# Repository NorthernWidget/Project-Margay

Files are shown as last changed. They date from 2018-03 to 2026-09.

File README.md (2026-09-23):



# Project-Margay

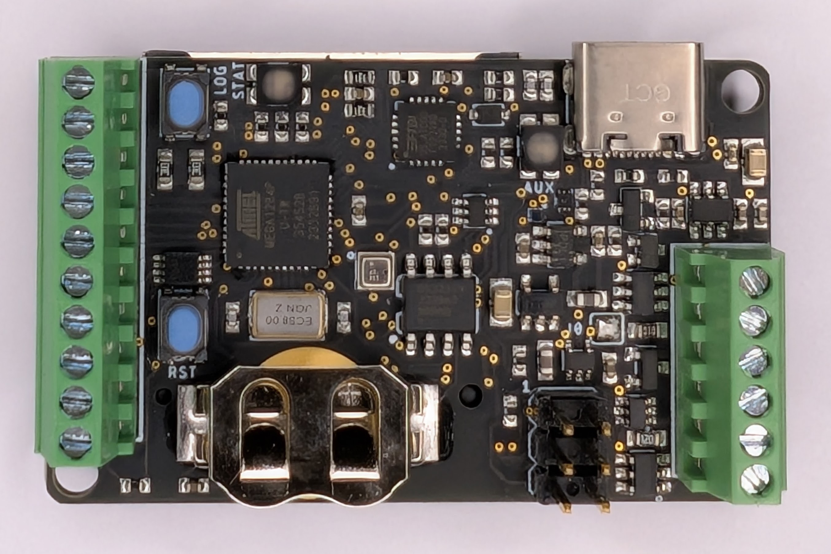
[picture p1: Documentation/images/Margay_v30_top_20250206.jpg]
Margay v3.0, top view


***Margay data logger v3.0.*** *Top side showing ATmega1284p processor, USB-C connector, screw terminal I/O on both sides, and LOG/STAT/RST buttons.*

Project Margay is a micro-scale environmental data logger based on the ALog series. It trades I/O capabilities for cost and size, resulting in a simple yet capable logger.

## Citation

If you use this data logger in a publication, please cite (temporary citation until a dedicated Margay paper is published):

**Wickert, A. D., K. R. Barnhart, W. H. Armstrong, M. Romero, B. Schulz, G.-H. C. Ng, C. T. Sandell, J. La Frenierre, S. B. Penprase, M. Van Wyk de Vries, and K. R. MacGregor (2024), [Automated ablation stakes to constrain temperature-index melt models](https://doi.org/10.1017/aog.2024.21), *Ann. Glaciol.*, *64*(92), 425–438, doi:10.1017/aog.2024.21.**

## Namesake

Due to its small size and adaptability to its environment, Project Margay owes its name to the small Margay cat native to the forests of Central and South America.

A margay, yawning

***A yawning margay cat***

## Technical Specifications

### Electronic Hardware
This includes a description of the PCB and component functionality

#### Features:
* ATMega1284p Processor
* 3.3v Logic
* On board full size SD card (for ease of field use)
* Extremely low sleep current
* Input voltage designed for use with easy to find alkaline batteries
* 0.1" Pitch headers can be populated with header pins and placed on a breadboard for prototyping

### Current iteration:

#### v3.0

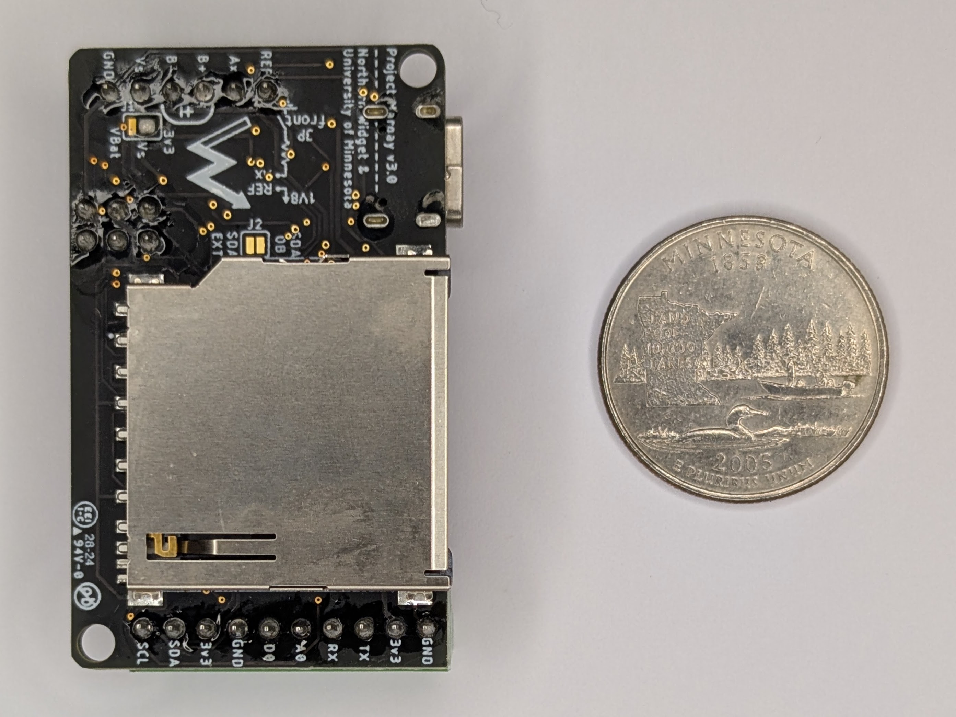
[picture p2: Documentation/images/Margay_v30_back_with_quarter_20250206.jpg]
Margay v3.0, back with SD card and quarter for scale


***Margay data logger v3.0, back side.*** *Full-size SD card for data storage. US quarter (24.3 mm diameter) shown for scale.*

Changes from v2.2:
* USB-C connector (replacing micro-USB)
* Increased mounting hole sizes to fit #4 screws
* Moved one passive component to accommodate the larger holes

All electrical specifications and pinout are otherwise identical to v2.2. Annotated pinout diagrams are in the [Pinout and board interfaces section below](#pinout-and-board-interfaces) and apply directly to v3.0.

### Past Iterations:

#### Features:
* ATMega644p Processor
* 3.3v Logic
* On board full size SD card (for ease of field use)
* Extremely low sleep current
* Input voltage designed for use with easy to find alkaline batteries
* 0.1" Pitch headers can be populated with header pins and placed on a breadboard for prototyping

#### v0.0 (Retired)
**Features** <br>
I<sub>Q</sub> = 1.6mA <br>
I<sub>out</sub> = 50mA, max (Regulated power supplied to sensors) <br>
V<sub>in</sub> = 3.3 ~ 5.5v <br>

**IO**:
* 1 I2C Bus
* 1 SPI Bus, with up to 2 CS pins
* 1 PWM Channel (output configurable to 3.3v or VBat via a jumper on bottom of board)
* RGB Status LED
* Auxiliary LED
* Reset Button
* Reconfigurable Button

#### v1.0
**Features** <br>
I<sub>Q</sub> = 2.5&mu;A <br>
I<sub>out</sub> = 50mA, max (Regulated power supplied to sensors) <br>
V<sub>in</sub> = 3.3 ~ 5.5v (Reverse polarity protected) <br>

**IO**
* 1 ADC, 18 bit
* 1 I<sup>2</sup>C Bus
* 1 SPI Bus, with up to 2 CS pins
* 1 PWM Channel (output configurable to 3.3v or VBat via a jumper on bottom of board)
* RGB Status LED
* Auxiliary LED
* Reset Button
* Reconfigurable Button

#### v2.0
**Features** <br>
I<sub>Q</sub> = <2.5&mu;A (Estimated) <br>
I<sub>out</sub> = 200mA, max (Regulated power supplied to sensors) <br>
V<sub>in</sub> = 3.3 ~ 5.5v (Reverse polarity protected) <br>

**IO**
* 1 ADC, 18 bit
* 1 I<sup>2</sup>C Bus
* 1 UART Channel
* 2 GPIO Pins (one configurable as an 8 bit ADC)
* 1 PWM Channel (output configurable to 3.3v or VBat via a jumper on bottom of board)
* RGB Status LED
* Auxiliary LED
* Reset Button
* Reconfigurable Button

#### v2.2
**Features** <br>
I<sub>Q</sub> = 1.68&mu;A <br>
I<sub>out</sub> = 200mA, max (Regulated power supplied to sensors) <br>
V<sub>in</sub> = 3.3 ~ 5.5v (Reverse polarity protected) <br>

**IO**
* 1 ADC, 18 bit
* 1 I<sup>2</sup>C Bus
* 1 UART Channel
* 2 GPIO Pins (one configurable as an 8 bit ADC)
* 1 PWM Channel (output configurable to 3.3v or VBat via a jumper on bottom of board)
* RGB Status LED
* Auxiliary LED
* Reset Button
* Reconfigurable Button

### Electronic Software and Firmware

* Programmable using the Arduino IDE https://www.arduino.cc/en/software
* Custom bootloader and board definition for ATMega1284p available via https://github.com/NorthernWidget/Arduino_Boards
* Custom libraries from Northern Widget and the open-source community
  * Primary data-logger functions
  * Libraries available with each sensor, exposing a standard interface
* Open-source licensing via GNU GPL 3.0

### Pinout and board interfaces
Pinout is listed on bottom of board. The pinout is identical across v2.2 and v3.0.

Margay v2.2, top annotated

***Margay data logger with pins, connectors, and interactive items annotated, top side.***

**Pins are colored following this convention:**
* Ground: black
* Positive voltage: red
* Universal Serial Asynchronous Receiver--Transmitter (UART or USART) bus: blue
* Digital I/O: gray
* Analog measurement system: green
* I2C bus: purple

*The jumper on the front of the board, to the right of "B+" and "Ax", connects an on-board reference resistor (10 kOhm in our builds) with the analog pin Ax to create a voltage divider in which the sensor between Ax and REF is on the GND side of the voltage divider.*

Margay v2.2, bottom annotated

***Margay data logger annotated, bottom side.*** This is where the labels for the above pins are printed.

In this pinout, the name of each pin is shown, as well as the group of pins which it belongs to, a detailed description of the pins and callouts follows:

#### Pins:
* 3v3, the switched 3.3v output rail, this rail can be turned on and off to disconnect power consumptive external devices
* GND, the main output ground
* BAT+, the positive connection for the battery line, voltage range 3.3v ~ 5.5v
* BAT-, Negative battery connection, ***note: this pin is NOT interchangeable with GND, as BAT- is reverse voltage protected to prevent damage from plugging the battery in backwards***
* Vs, this is the switched PWM output, the voltage of this output is determined by a solder jumper on the bottom of the board, controlled by `VSwitch_Pin` - See information of limits and configuration below

* MOSI, this is the master out, slave in, pin for the SPI bus, which doubles as **D5** when SPI and SD card are not used
* MISO, this is the master in, slave out, pin for the SPI bus, which doubles as **D6** when SPI and SD card are not used
* SCK, this is the clock line for the SPI bus, which doubles as **D7** when SPI and SD card are not used
* CS, this is the chip select pin for the SPI bus, which doubles as both **D11** and **INT1** when external SPI is not used (Can be used even when SD card is used)

* SCL, this is the dedicated serial clock line for the I2C bus
* SDA, this is the dedicated serial data line for the I2C bus

#### Callouts:
1. This is the auxiliary LED, which indicate TX and RX status using red and blue channels, green channel is controlled by `BuiltInLED` pin
2. This is the USB connection (USB-C on v3.0; micro-USB on v2.x), which can be used for both programming via the Arduino IDE and serial monitoring
3. This is the primary RGB status LED, where the individual channels are controlled by **D15**, **D14**, and **D13**
4. This is the reconfigurable push-button, generally used to initiate logging, it is read by `LogInt` pin
5. This is the hardware reset button, which will force the micro to return to the initial state after code upload
6. This is the ICSP header, which can be used to burn the bootloader to the board or write programs to the chip without using the USB and bootloader

#### Onboard Pins:
Pin Name | Pin Number (v0.0) | Pin Number (v1.0) | Pin Number (v2.x) | Function
-------- | ----------------- | ----------------- | ----------------- | --------
`SD_CS` | D4 | D4 | D4 | Chip select pin on SD card
`SD_CD` | D1 | D1 | D1 | Card detection pin for SD card, active low, AUX power must be on to use
`BuiltInLED` | D19 | D20 | D20 | Connected to green channel on **AUX** LED, on when pin is low
`RedLED` | D13 | D13 | D13 | Connected to red channel on **STAT** LED, on when pin is low
`GreenLED` | D15 | D15 | D15 | Connected to green channel on **STAT** LED, on when pin is low
`BlueLED` | D14 | D14 | D14 | Connected to blue channel on **STAT** LED, on when pin is low
`VRef_Pin` | A2 | A2 | A3 | Analog pin to read 1.8v on board reference, AUX power must be on to use
`ThermSensePin` | A1 | A1 | A1 | Analog pin to read thermistor voltage divider, AUX power must be on to use
`BatSensePin` | A0 | A0 | A2 | Analog pin to read battery voltage divider, AUX power must be on to use
`VSwitch_Pin` | D3 | D3 | D12 | Connected to MOSFET driver for **Vs** pin, active low
`Ext3v3Ctrl` | D12 | D19 | D22 | Turns on AUX power, active low
`I2C_SW` | N/A | D12 | D21 | Switches between on board I2C and external I2C
`PG` | D18 | D18 | D18 | Power good pin from core 3v3, can be used to test if core 3v3 is stable, pulled low when power is not stable
`ExtInt` | D11 | D11 | D11 | External interrupt and external chip select pin
`RTCInt` | D10 | D10 | D2 | Interrupt connected to RTC /INT line, active low
`LogInt` | D2 | D2 | A4 | Interrupt connected to **LOG** button, active low

#### VSwitch Power Limits/Configuration:
Jumper Selected | Logger Power Source | Current Limit, Avg [mA] | Power Limit, Avg [W] 
--------------- | ------------------- | ---------------------- | -------------------- 
VMain | USB | 220 | 0.5 
VMain | Bat | 500 | 2.25 
3v3 | USB | 220 | 0.5 
3v3 | Bat | 450 | 2.0

Note: Instantaneous current may exceed these values — these values correspond to the time-averaged power consumption. This distinction is most important when driving a load via PWM.

## On-board Devices

### I2C

| **Device** 	| **Default address** 	| **Reprogrammable address** 	| **Function** 	|
|---	|---	|---	|---	|
| [DS3231](https://github.com/NorthernWidget/DS3231_Logger) 	| 0x68 	| N 	| Real-time clock 	|
| [MCP3421](https://github.com/NorthernWidget/MCP3421) 	| 0x6A 	| N 	| ADC 	|
| [BME280](https://github.com/NorthernWidget/BME_Library) 	| 0x77 	| N 	| On-board barometric pressure, temperature, and relative humidity 	|

### SPI

* SD Card

### UART (USART)

* FTDI USB-Serial converter

## Assembly

Assembling this data logger is possible by hand with sufficient skill and the following tools:
* Temperature-controlled soldering iron
* Hot-air rework station
* Equipment for stenciling with solder paste
* ESD-safe tweezers and workstation
* Solder wick

Mechanized assembly by a professional circuit-board assembly house, which is available in many parts of the world, may be preferred due to the complexity of this data logger board.

## Programming

### Downloading and installing the Arduino IDE

Go to https://www.arduino.cc/en/software and download the IDE for your operating system. The web editor does not support custom libraries and will not work for this project. Install the IDE and open it before continuing.

For additional setup guidance, see the [Northern Widget tutorial](https://docs.northernwidget.com/tutorial/).

### Installing the bootloader

Before a data logger can receive programs via USB, it must have a *bootloader* installed. You can read more about bootloaders here: https://www.arduino.cc/en/Hacking/Bootloader.

The bootloader is loaded via the 6-pin ICSP (ISP) header using an in-circuit system programmer. Many programmers work:
* The official [AVR ISP mkII](http://ww1.microchip.com/downloads/en/DeviceDoc/Atmel-42093-AVR-ISP-mkII_UserGuide.pdf) (no longer produced but available used)
* Using an [Arduino as an ISP](https://www.arduino.cc/en/tutorial/arduinoISP)
* The versatile [Olimex AVR-ISP-MK2](https://www.olimex.com/Products/AVR/Programmers/AVR-ISP-MK2/open-source-hardware)
* The [Adafruit USBtinyISP](https://www.adafruit.com/product/46)

***Important note for Linux users:*** You must supply permissions to the Arduino IDE for it to use the ICSP, or run the IDE with `sudo`.

To install the bootloader:

1. Open the Arduino IDE and install the Northern Widget board definitions: https://github.com/NorthernWidget/Arduino_Boards — the Margay uses the **TLog v1** definition.
2. Select ***ATMega1284p 8MHz*** under *Tools → Board → Northern Widget Boards*.
3. Plug the Margay into your computer via USB (USB-C on v3.0; micro-USB on v2.x) to power it.
4. Plug your ISP into your computer and onto the 6-pin ICSP header. The ribbon cable should face away from the board; if programming fails, try flipping the connector.
5. Go to *Tools → Programmer* and select your programmer.
6. Go to *Tools → Burn Bootloader*. Within a few seconds you will see a success or failure message.

***Note: Download and install drivers for your ISP before use.***

### Hardware test sketch

The [`MargaySetup`](Software/MargaySetup/MargaySetup.ino) sketch verifies every hardware subsystem over the serial monitor at 38400 baud. It also handles serial number programming (`SN Set` / `SN Read`). See the [Full hardware test command reference](#full-hardware-test-command-reference) table below.

Install these libraries before uploading (see [Arduino manual install guide](https://www.arduino.cc/en/Guide/Libraries)):
* [DS3231](https://github.com/NorthernWidget/DS3231) — real-time clock
* [MCP3421](https://github.com/NorthernWidget/MCP3421) — on-board ADC
* SD — bundled with the Arduino IDE

### Data logging

For data logging, use the [Margay_Library](https://github.com/NorthernWidget/Margay_Library). It manages sleep/wake, SD writes, RTC reads, and on-board sensor sampling automatically. See the [Sample code](#sample-code) section below.

Install these libraries manually from GitHub (see [Arduino manual install guide](https://www.arduino.cc/en/Guide/Libraries)):
* [Margay_Library](https://github.com/NorthernWidget/Margay_Library)
* [DS3231_Logger](https://github.com/NorthernWidget/DS3231_Logger)
* [NW_MCP3421](https://github.com/NorthernWidget/MCP3421)
* [BME](https://github.com/NorthernWidget/BME_Library)
* [SdFat](https://github.com/greiman/SdFat) — available via *Tools → Manage Libraries*

### Setting the serial number

Upload the [MargaySetup](Software/MargaySetup/MargaySetup.ino) sketch, open the serial monitor at **38400 baud**, and type `SN Set` followed by a carriage return or newline. You will be prompted for three 4-digit hexadecimal fields:
* **Board type:** `0x4D03` for Margay v3.0; `0x4D02` for v2.2 (full series: v0.0 = `0x4D00`, v1.0 = `0x4D01`). If you built your own board, do not use these codes — they are reserved for Northern Widget recordkeeping.
* **Group ID:** Used to denote collaborative projects vs. internal use vs. general sales.
* **Unique ID:** A monotonically increasing number.

To read back the serial number, type `SN Read`.

### Full hardware test command reference

The same sketch provides a serial command interface at **38400 baud** for testing all individual hardware subsystems. Send a command followed by a carriage return or newline. Continuous tests run until a carriage return is sent to stop them.

Command | Description
--------|------------
`SD` | Writes a random value and short string to the SD card, reads it back, reports PASS/FAIL
`Clock` | Sets the RTC to a known time, waits 5 seconds, reads it back, reports PASS/FAIL
`I2C` | Scans the I2C bus and prints the address of every device found
`ADC Disp` | Continuously prints voltages for the on-board reference, thermistor, battery, and external ADC (Ax)
`IO` | Toggles the VSwitch and ExtInt pins
`PG` | Reads the Power Good pin and reports PASS/FAIL
`Power` | Toggles the external 3.3V rail on and off
`Button` | Waits 2 seconds for the Log button to be pressed and reports if detected
`LED` | Cycles through each channel of the RGB and AUX LEDs
`SN Set` | Sets the serial number in EEPROM (see above)
`SN Read` | Reads back the serial number from EEPROM

### Using Custom Software (Developer)
As we provide all information about on board pins and their functionality, it is easy for a user to write their own code in the Arduino IDE to leverage the hardware capabilities of the Margay to whatever degree is desired. To do this, the Northern Widget board file can be used (as described above), or the **[MightyCore](https://github.com/MCUdude/MightyCore)** board files can be used. These are the board files the Northern Widget ones were based on, but allow for more compilation options for the user. Full instructions for installation and use are provided on the MightyCore GitHub page.

For **v2.0 and later** (ATmega1284p), the recommended settings are:

Setting | Value
--------|------
`Board` | `ATmega1284`
`Pinout` | `Standard`
`Clock` | `8MHz External`
`Compiler LTO` | `Disabled`
`Variant` | `1284P`
`BOD` | `2.7v`

For **v0.0 and v1.0** (ATmega644p), the recommended settings are:

Setting | Value
--------|------
`Board` | `ATmega644`
`Pinout` | `Standard`
`Clock` | `8MHz External`
`Compiler LTO` | `Disabled`
`Variant` | `644P / 644PA`
`BOD` | `2.7v`

#### Sample code

`Margay_NoSensors.ino`

```c++
#include "Margay.h"
// Include any sensor libraries.
// The Northern Widget standard interface is demonstrated here.
//Sensor mySensor;

// Instantiate classes
// Sensor mySensor; (for any Northern Widget standard sensor library)
Margay Logger(MODEL_3v0);  // defaults to MODEL_3v0 if omitted; update for older hardware

// Empty header to start; will include sensor labels and information
String header;

// I2CVals for sensors
// Add these for any sensors that you attach
// These are used in the I2C device check (for the warning light)
// But at the time of writing, the logger should still work without this.
uint8_t I2CVals[] = {};

// Number of seconds between readings
// The Watchdog timer will automatically reset the logger after approximately 36 minutes.
// We recommend logging intervals of 30 minutes (1800 s) or less.
// Intervals that divide cleanly into hours are strongly preferable.
uint32_t updateRate = 60;

void setup(){
    // No sensors attached; header may remain empty.
    // header = header + mySensor.getHeader(); // + nextSensor.getHeader() + ...
    Logger.begin(I2CVals, sizeof(I2CVals), header);
}

void loop(){
    Logger.run(update, updateRate);
}

String update() {
    initialize();
    //return mySensor.getString(); // If a sensor were attached
    return ""; // Empty string for this example: no sensors attached
}

void initialize(){
    //mySensor.begin(); // For any Northern Widget sensor
                        // Other libraries may have different standards
}
```

### Reference

A full index of the public variables and functions within the Margay data logger library is available at https://github.com/NorthernWidget/Margay_Library.

## Field operator's guide

The [Margay Operations Guide (PDF)](Documentation/MargayGuide_20220622.pdf) covers field operation in printable form.

***Note: Logger will not be able to wake up unless the clock (RTC) is powered.***

The RTC (DS3231M) is powered exclusively by the **CR1220 coin cell** mounted on the back of the board. This is a separate power source from the main battery pack — the logger cannot wake from sleep if the coin cell is missing, dead, or making poor contact, even if the main batteries are fully charged.

**Cold-weather deployments:** Standard CR1220 cells (Li-MnO₂) are rated to −20°C and may fail at temperatures common in subarctic and arctic field sites. Observed clock failures in cold deployments are likely caused by the coin cell browning out at low temperature. The coin cell is the sole RTC power source during sleep — the main battery does not power the RTC between readings.

- For deployments down to −30°C: replace the CR1220 with a [**Panasonic BR1220**](https://www.digikey.com/en/products/detail/panasonic-bsg/BR1220-BE/447510) (Li-CFx chemistry, rated −30°C to +85°C, drop-in replacement).
- For deployments below −30°C: use a [**Panasonic BR1225A**](https://www.digikey.com/en/products/detail/panasonic-bsg/BR1225A-BE/447512) (Li-CFx, rated −40°C to +125°C). The BR1225A is 2.5mm thick vs. 2.0mm for the 1220 — the on-board holder (Linx BAT-HLD-012-SMT) officially supports both sizes.

### Logging Start
Logging begins automatically once power is applied. If error conditions are found, they will be indicated by status lights, but the logger will attempt to continue if possible. The following should represent the light sequence.

- On power application
	- `AUX` light will illuminate **green**, will stay on while testing
- After testing is complete
	- `AUX` light will turn **off**
	- `STAT` light will illuminate with various colors depending on the status of the logger
    - See "Status Codes" under "Troubleshooting" below for details
	- `STAT` light will flash **long-short-short blue** to indicate logging has begun (older firmware: 5× long blue flash)

### Checking recorded data
1. After initializing, wait 2–3 minutes.
2. Follow the **SD card swap / Download** steps below to retrieve the SD card.
3. Verify that all data are recorded at the proper (UTC) time.
4. Verify that valid values are recorded for all sensors.
5. If files are not present, replace the SD card, check all connections, and re-initialize.

### SD card swap
1. Turn battery pack **off**.
2. Remove SD card. Label it and put it somewhere safe.
3. Insert a freshly labeled SD card.
4. Turn battery pack on and re-initialize.

### Downloading data
1. Turn battery pack **off**.
2. Remove SD card.
3. Insert SD card in computer.
4. Navigate to the most recent log file: `NW → <serial_number> → Log<number>.txt`
5. Save the file in a well-labeled and organized location.
6. Safely eject the SD card.
7. Re-initialize the logger.

### Troubleshooting
If an error code is received try the following steps:

**General**
* Disconnect and reconnect power, both USB and battery ([Turn it off and back on again](https://i.imgur.com/Yj6dB3W.gif))
* Verify the quality of all screw terminal connections by gently tugging on the wires and making sure they stay in place, if not, remove and re-tighten the connection
* Ensure sensors and/or cables are not damaged, this can result in shorts or other problems
* Make sure batteries have sufficient voltage to run the logger, when the battery voltage drops below *3.3v*, malfunctions can occur

#### Status Codes

The second LED (STAT) will have one of the colors below.

**Green**: All systems check out OK, logging will proceed

**Orange**: A sensor system is not registering properly, some sensor data may be missing or incorrect
* Verify correct polarity of sensor connection
* Ensure the right sensor is connected
* Verify the screw terminals are well connected to the wires (a loose connection can cause a failure)
* Make sure battery power is applied, some sensors can fail otherwise

**Cyan**: Clock time is incorrect, but logger is otherwise working correctly
* Connect the logger to a computer and reset the clock using the [Northern Widget Time Set GUI](https://github.com/NorthernWidget/SetTime_GUI)
* Note and record the wrong time if the logger has been out in the field, alongside the current (correct) time, to correct the prior measurements

**Pink**: (looks like purple to some people): SD card is not inserted
* Insert the SD card, or make sure card is fully seated

**Red**: Critical on-board component is not functioning correctly, such as SD card or clock; Logging will likely not be able to proceed
* Attempt power cycle
* Try different SD card
* Disconnect all sensors
* If none of the previous steps remove the red light, contact [Northern Widget](http://www.northernwidget.com/contact/) for further support

**Yellow, Fast Blinking**: <50% battery capacity
* Replace batteries

**Red, Fast Blinking**: Batteries <3.3V, voltage too low to properly function
* *If* this error occurs while also connected over USB, check proper connection of batteries
* Replace batteries

## Developer Notes

+ (**v0.0 / v1.0 only**) When using power from the external rail (the 3v3 on the screw terminals) it is always advised to have a battery connected to the board, even if connected via USB. The USB connection is able to power the core components, but not the external rail. This was resolved in v2.0.
+ (**v0.0 / v1.0 only**) When using I<sup>2</sup>C on the device, external pullups (4.7k&Omega; ~ 10k&Omega;) are required. If using devices strictly on-board, the internal pullups on the ATmega may be sufficient, but adding the capacitance of an external sensor cable often causes problems since the internal pullups are very weak. Dedicated switchable on-board pullups were added in v2.0.
+ (**All models**) The external power rails and the switched battery rail should be enabled in hardware by default, however, it is our recommendation to explicitly define these pins (`Ext3v3Ctrl`) as outputs and drive them `LOW` even if you never intend to switch them on and off. This prevents the rails from inadvertently being turned off due to a transient on the floating control line.

## NW-Device-Specification schema

Margay's serial number scheme is [Schema 0](https://github.com/NorthernWidget/NW-Device-Specification) — the original 8-byte NW identity block, predating the formal specification. Schema 1 formalizes it as Page 0 and defines a putative Page 1 for the case where Margay acts as an I²C peripheral of a higher-level device (e.g., a cellular gateway or satellite modem). **Margay has no current I²C peripheral interface; Page 1 is hypothetical.**

### Current EEPROM serial number (Schema 0)

Eight bytes at `EEPROM[length−8]` through `EEPROM[length−1]` (bytes 4088–4095 on the ATmega1284P), big-endian uint16 per field, written by MargaySetup `SN Set`:

| Bytes | Field | Example (Margay v3.0) |
|---|---|---|
| 0–1 | Board type | `0x4D03` (`'M'` = 0x4D, revision 3) |
| 2–3 | Group ID | operator-assigned |
| 4–5 | Unique ID | monotonically increasing |
| 6–7 | FirmwareID | `0x0000` (hardcoded) |

Displayed as `XXXX-XXXX-XXXX-XXXX` in hex (e.g. `4D03-0001-0042-0000`).

### Proposed register layout (NW-Device-Specification Schema 1)

**Page 0 (0x00–0x1F) — Identity (EEPROM)**

Block 2 directly formalizes the existing 8-byte serial number with no data loss. The board type encoding (`'M'` = 0x4D high byte, revision index low byte) already follows the Schema 1 convention.

```
Block 0 (0x00–0x07)   Core identity
  0x00        0x01                           Schema (NW-Device-Specification v1)
  0x01–0x06   'M','a','r','g','a','y'        Device name (6 bytes)
  0x07        0x00                           Reserved

Block 1 (0x08–0x0F)   Version
  0x08        HW major
  0x09        HW minor
  0x0A        FW patch
  0x0B–0x0D   0x00,0x00,0x00                Unused (combined repo convention)
  0x0E–0x0F   0x00,0x00                     Reserved

Block 2 (0x10–0x17)   Serial number
  0x10–0x11   0x4D,0x03                     Board type ('M'=0x4D, revision index)
  0x12–0x13   [manufacture]                 Group ID
  0x14–0x15   [manufacture]                 Unique ID
  0x16–0x17   0x00,0x00                     FirmwareID (legacy, reserved)

Block 3 (0x18–0x1F)   Integrity + administration
  0x18–0x1C   0x00 ×5                       Reserved
  0x1D        0x00                          Magic byte (reserved; purpose TBD)
  0x1E        [computed]                    CRC-8 of bytes 0x00–0x1D
  0x1F        0x00                          I²C address (unassigned; Margay is
                                            currently I²C controller only)
```

**Page 1 (0x20–0x3F) — Logger status (SRAM) — HYPOTHETICAL**

Margay is currently an I²C controller only and has no peripheral interface. This layout is proposed for the case where a future version acts as an I²C peripheral of a higher-level device. A natural peripheral address would be `0x4D` (ASCII `'M'`).

Subsystem table (same index rules as a sensor's chip table):

| Index | Subsystem |
|---|---|
| 0 | SD card |
| 1 | DS3231M RTC |
| 2 | BME280 onboard environment |
| 3 | Sensor bus |
| 4 | Battery |

Block 0 (0x20–0x27) is the universal block defined by [NW-Device-Specification](https://github.com/NorthernWidget/NW-Device-Specification#page-1-sensor-data): status (ready, per-chip fault bits, pan-fault), control (trigger, chip select, sleep), reading counter, device config byte at 0x26, latched fault code at 0x27. Device data begins at 0x28. Config (0x26): reserved. Logger state continues on Page 3 (0x60–0x7F).

```
Block 1 (0x28–0x2F)   Battery
  0x28        Bat %        uint8, 0–100
  0x29–0x2A   Bat voltage  uint16, 0.01 V
  0x2B–0x2F   Reserved

Block 2 (0x30–0x37)   BME280 — onboard environment
  0x30–0x31   Temperature  int16, 0.01 °C
  0x32–0x33   Humidity     uint16, 0.01 %RH
  0x34–0x37   Pressure     uint32, 0.01 hPa

Block 3 (0x38–0x3F)   DS3231M — RTC
  0x38–0x3B   Timestamp    uint32, Unix time (seconds since 1970-01-01 UTC)
  0x3C–0x3D   Temperature  int16, 0.01 °C
  0x3E–0x3F   Reserved

Page 3, Block 0 (0x60–0x67)   Logger state
  0x60–0x61   Ext interrupts  uint16, accumulated count
  0x62–0x63   Log file #      uint16
  0x64–0x67   Log interval    uint32, seconds
```

No Page 2. Battery discharge curve coefficients and Steinhart–Hart thermistor constants are hardcoded in the library; no per-unit calibration is stored.

## NW-Device-Specification — Schema 1, Page 0

Implements [NW-Device-Specification](https://github.com/NorthernWidget/NW-Device-Specification) Schema 1. The 32-byte identity block (Page 0) is stored at the top of EEPROM:

```
Block 0:  Schema=0x01, Name='M','a','r','g','a','y',0x00
Block 1:  HW major=[mfr], HW minor=[mfr], FW patch=[mfr], 0x00,0x00,0x00, Reserved
Block 2:  Board type=0x4D03 ('M'=0x4D, rev 3), Group ID=[mfr], Unique ID=[mfr], FirmwareID=0x0000
Block 3:  Reserved, Magic=0x4E, CRC=[computed], I2C address=0x00 (controller; no peripheral interface)
```

## Acknowledgments

Support for this project provided by:

UMN ESCI

NSF

<br/>
<br/>
<br />Hardware and documentation are licensed under a <a rel="license" href="http://creativecommons.org/licenses/by-sa/4.0/">Creative Commons Attribution-ShareAlike 4.0 International License</a>. Software in the <code>Software/</code> directory is licensed under the <a href="https://www.gnu.org/licenses/gpl-3.0.en.html">GNU General Public License v3</a>.

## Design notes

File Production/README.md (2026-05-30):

# Production

This folder contains bills of materials, Gerber packages, and assembly files for each Margay hardware version.

## Contents

### Bills of Materials

| File | Version | Date | Notes |
|---|---|---|---|
| `Margay_BoM_2v2_-2021-05-10.csv` | v2.2 | 2021-05-10 | Assembly BoM (soldered components) |
| `Margay_BoM_2v3_-_2023-03-16.csv` | v3.0 day 1 | 2023-03-16 | "v2.3" was a one-day working name; board became v3.0 |
| `Margay_BoM_3v0_-_2023-03-17.csv` | v3.0 | 2023-03-17 | Assembly BoM: soldered components; used for Caltronics production run |
| `Margay_BoM_3v0_board_-_2023-03-17.csv` | v3.0 | 2023-03-17 | Board BoM: non-soldered items inserted into the board (coin cell, SD card) |

### Gerber and assembly packages

| File | Version | Date | Notes |
|---|---|---|---|
| `Margay_3v0_proto_2023-05-01.zip` | v3.0 proto | 2023-05-01 | Prototype Gerber run; detailed top silkscreen; same copper as production |
| `Margay_3v0_2023-08-01.zip` | v3.0 production | 2023-08-01 | Production Gerbers used for Caltronics assembly run |
| `Margay_3v0.mnt` | v3.0 | — | Pick-and-place / centroid file for SMT assembly |

### Quotes

| File | Date | Notes |
|---|---|---|
| `CaltronicsQuote_2023-08-01.zip` | 2023-08-01 | Assembly quote from Caltronics for the v3.0 production run |

---

## Submitting to a fab house

Each Gerber ZIP contains a `CAMOutputs/` folder exported from Eagle with the following structure:

```
CAMOutputs/
  Assembly/
    Margay.txt          — BoM (Eagle-exported)
    PnP_Margay_front.txt — Pick-and-place, top side
    PnP_Margay_back.txt  — Pick-and-place, bottom side
  DrillFiles/
    drill_1_16.xln      — Excellon drill file
  GerberFiles/
    copper_top.gbr / copper_bottom.gbr
    silkscreen_top.gbr / silkscreen_bottom.gbr
    soldermask_top.gbr / soldermask_bottom.gbr
    solderpaste_top.gbr / solderpaste_bottom.gbr
    profile.gbr         — Board outline
    gerber_job.gbrjob   — Job file (KiCAD/Gerber viewer metadata)
```

Submit the full ZIP to the PCB fabricator. For assembly, additionally provide the pick-and-place files and the assembly BoM CSV (`Margay_BoM_3v0_-_2023-03-17.csv`). The board BoM (`Margay_BoM_3v0_board_-_2023-03-17.csv`) covers the coin cell and SD card inserted after assembly and is not sent to the fab house.

> **Note:** When these packages are restructured into versioned subdirectories, each subfolder will contain its own README with version-specific notes.

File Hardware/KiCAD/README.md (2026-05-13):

# Hardware/Margay_2 — Eagle-to-KiCAD port, current working version (work in progress)

This is the most current KiCAD design for the Margay v3.0, representing the active Eagle-to-KiCAD port.

**Current state:** schematic is split across three hierarchical sheets (`Margay_1/2/3.kicad_sch`) imported from Eagle via `Margay-eagle-import.kicad_sym`. PCB layout (`Margay.kicad_pcb`) is also present. Both are works in progress and have not been verified against the v3.0 production Gerbers.

Tracking issue: https://github.com/NorthernWidget/Project-Margay/issues/41

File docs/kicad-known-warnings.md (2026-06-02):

# KiCAD "Update PCB from Schematic" — Known Warnings

Running **Update PCB from Schematic** in KiCAD consistently produces 8 warnings of the form "No net found for symbol X pin Y." All are benign and carry through from the original Eagle design.

## The 8 warnings

| Component | Pin | Reason |
|---|-----|---|
| J4 (USB-C, GCT USB4105-GF-A) | M1 | Mechanical mounting tab — no electrical net by design |
| J4 (USB-C, GCT USB4105-GF-A) | M2 | Mechanical mounting tab — no electrical net by design |
| J4 (USB-C, GCT USB4105-GF-A) | M3 | Mechanical mounting tab — no electrical net by design |
| J4 (USB-C, GCT USB4105-GF-A) | M4 | Mechanical mounting tab — no electrical net by design |
| U6 (TPS797 LDO) | 3 (EN) | EN pin not modeled in Eagle-imported symbol; pad exists on footprint but has no symbol pin. EN floating = always on — intentional. |
| U10 (TLV3691 comparator) | 5 (HYST) | Hysteresis pin intentionally left floating — no external hysteresis resistor used |
| U11 (MIC9409 load switch) | 3 (FLAG) | Open-drain fault flag output intentionally unused |

## Why they can't be easily suppressed

- **J4 M1–M4**: The M pins exist in the Eagle-imported symbol but are not broken out visibly on the schematic sheet. No-connect markers cannot be placed on invisible pins.
- **U6 pin 3**: The EN pin is absent from the Eagle-imported TPS797 symbol entirely. Adding it would require editing the symbol and re-wiring the schematic instance.
- **U10 pin 5, U11 pin 3**: Pins exist in the symbol but are not visible on the schematic sheet. No-connect markers could suppress these if the pins are exposed.

## What to do

Nothing — these warnings do not affect manufacturing output, DRC, or board function. They are accepted as known informational noise from the Eagle→KiCAD migration.

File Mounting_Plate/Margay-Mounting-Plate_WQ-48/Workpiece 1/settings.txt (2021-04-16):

Material type: ABS
Material dimensions: 190.5 mm x 139.7 mm x 3.175 mm
Bit: 0.0625 in, Upcut

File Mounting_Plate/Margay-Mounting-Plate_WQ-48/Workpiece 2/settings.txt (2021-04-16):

Material type: ABS
Material dimensions: 139.7 mm x 190.5 mm x 3.175 mm
Bit: 0.0625 in, Upcut

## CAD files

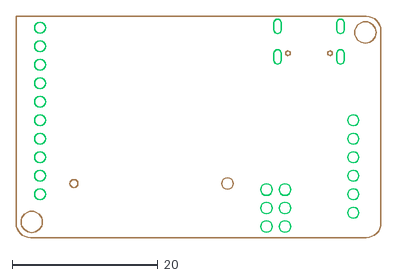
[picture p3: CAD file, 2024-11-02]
Hardware/Margay_Outline.dxf
50.1 x 30.4

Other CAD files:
3Dprint/BatteryMount_Strap.SLDPRT
Hardware/Margay_PCB_3v0.STL
3Dprint/BatteryMount_WH10.SLDPRT
3Dprint/MargayMount_WH02_lid.SLDPRT
3Dprint/MargayMount_WH10.SLDPRT
3Dprint/StencilMount_Margay.SLDPRT
3Dprint/BatteryMount_Strap.STL
3Dprint/BatteryMount_WH10.STL
3Dprint/MargayMount_WH02_lid.STL
3Dprint/MargayMount_WH10.STL
3Dprint/StencilMount_Margay.STL

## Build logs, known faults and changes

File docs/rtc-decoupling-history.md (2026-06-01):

# RTC Power & Decoupling History

## Field Motivation

The Margay is a scientific data logger. Every record it produces is timestamped by the DS3231M RTC. When the RTC resets — losing the current time and returning to its epoch (January 1, 2000) — every subsequent log entry carries a wrong timestamp. The data is not merely imprecise; it is scientifically worthless. A sensor reading without a valid time cannot be placed in context, correlated with other measurements, or published.

Instruments are deployed in remote locations — stream gauges in wilderness watersheds, weather stations above treeline, soil sensors in arctic tundra — where servicing is expensive or seasonally impossible. A logger that silently resets its clock may accumulate weeks or months of invalid records before anyone notices. The fix is a site visit; the lost data is unrecoverable.

This is the engineering context behind the circuit changes described below. Keeping the clock running is not a convenience feature — it is the minimum condition for the instrument to do its job.

## Background

The DS3231M real-time clock has two power pins with distinct roles:

- **VCC** — primary power, supplied from the `3V3_AUX` switched rail. This rail is cut during MCU sleep to minimize quiescent current.
- **VBAT** — backup power, supplied from the CR1220 coin cell. The DS3231M switches to VBAT automatically when VCC falls below its internal threshold.

Because `3V3_AUX` is switched off every sleep cycle, the RTC transitions between VCC and VBAT every time the logger sleeps or wakes. The integrity of that handoff is the central concern of this page.

## Version History

### v0.0 and v1.0 — No VBAT decoupling

In the original designs, the VBAT pin connected directly to the coin cell with no decoupling capacitor. The net (`N$31` in the Eagle schematic) had only two members: `RTC1.VBAT` and `BT1.+`.

The `3V3_AUX` rail had minimal bulk decoupling — a single 1 µF capacitor at the LDO output.

**Effect:** When the MCU entered sleep and `3V3_AUX` collapsed, the DS3231M had to switch from VCC to VBAT with no local charge reservoir on VBAT to bridge the transition. The coin cell's ESR and the inductance of the PCB traces meant VBAT could dip transiently at exactly the moment the chip needed it. The DS3231M interpreted this as a power-on reset and cleared its time registers. Symptoms: logger woke up with the clock reset to its epoch (January 1, 2000), usually after a sleep cycle.

This was the primary cause of the RTC-reset failures observed in early field deployments.

### v2.1 — VBAT decoupling capacitor added

A 0.1 µF capacitor (C12, 0402) was added between the coin cell positive rail and the DS3231M VBAT pin. This matches the recommendation in the DS3231M datasheet.

The cap acts as a local charge reservoir: when VCC collapses, VBAT can supply instantaneous current from C12 while the coin cell's ESR settles, preventing the DS3231M from seeing a dip large enough to trigger a reset.

This change substantially reduced the frequency of RTC resets.

### v2.2 — Renumbering, more 3V3\_AUX bulk capacitance, switch topology change

- C12 was renumbered to **C19** (same value: 0.1 µF, 0402). The net was renamed from `N$31` to `VCOIN+`.
- `3V3_AUX` bulk decoupling grew significantly: from ~1 µF (v1.0) to ~21 µF total (C5 0.1 µF + C6 10 µF + C14 1 µF + C15 10 µF). A softer VCC collapse means a gentler handoff to VBAT.
- The `3V3_AUX` power switch was changed to **active-low control logic**, affecting the switching waveform on sleep entry.

### v3.0 — No change to RTC power circuit

v3.0 (USB-C, #4 mounting holes) made no changes to RTC power or decoupling. The circuit is identical to v2.2.

## Current Circuit (v2.2 / v3.0)

| Pin | Net | Connected to |
|-----|-----|---|
| VCC | `3V3_AUX` | Switched LDO output; cut during sleep |
| VBAT | `VCOIN+` | Coin cell (BT1) ∥ C19 (0.1 µF, 0402) |

The VBAT line is **not** connected to the always-on core 3.3 V rail.

## Remaining Vulnerability

The 0.1 µF cap on VBAT cannot sustain the RTC indefinitely. Two failure modes remain:

1. **Depleted or missing coin cell.** If VBAT has no source, C19 discharges in microseconds and the RTC resets.
2. **Cold-temperature coin cell brownout.** Standard CR1220 cells (Li-MnO₂) are rated to −20°C. Below that, internal resistance rises sharply and the cell may not be able to maintain VBAT above the DS3231M's minimum (2.3 V). This was the cause of observed clock failures in subarctic deployments.

Cold-temperature mitigation (available since v3.0): replace the CR1220 with a Panasonic BR1220 (rated −30°C) or BR1225A (rated −40°C, 2.5 mm thick — fits the Linx BAT-HLD-012-SMT holder). See the README for details.

## Proposed Future Improvement — VBAT Spoof (Issue #43)

To address both failure modes, v3.1 may route the always-on core 3.3 V rail to DS3231M VBAT through a Schottky diode (~0.3 V drop → ~3.0 V on VBAT, within the DS3231M's 2.3–5.5 V spec), with the existing C19 retained as the decoupling cap.

The coin cell would remain as a last-resort backup if the main pack is exhausted; the Schottky diode prevents backfeed into the core rail if the coin cell voltage ever exceeds it.

Pros and cons are discussed in [Issue #43](https://github.com/NorthernWidget/Project-Margay/issues/43).

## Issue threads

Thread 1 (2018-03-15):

Add Primary MOSFET

bschulz1701, 2018-03-15:
Add mosfet to switch the battery voltage input to all outputs (Vdd of comparators, and BatSense voltage divider)

bschulz1701, 2018-05-04:
Added along with 2 stage battery switch and secondary regulator

Closed 2018-05-04.

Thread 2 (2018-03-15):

Fix power setup for FTDI

bschulz1701, 2018-03-15:
Add mosfet/switching arraignment to get FTDI to be disconnected from power when micro USB voltage is not applied

Should disconnect 3v3out, and VCCIO

bschulz1701, 2018-04-10:
Fixed using the following circuit, where VCCIO, 3V3OUT, and RESET# lines of the FTDI converter are connected to 3V3_FTDI, this circuit allows for power to be supplied to the main 3V3 line by the converter in the FTDI (powered only over USB), however it prevents reverse power flow badness.

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

**Before fully closing issue, this circuit should be tested in hardware with the addition of LEDs**

Closed 2018-05-04.

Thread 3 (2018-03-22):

Fix address issue with ADC

bschulz1701, 2018-03-22:
on board ADC has same address as one used on TP-Downhole
Options:
-use different ADC hardware address (different part)
-be able to turn off external power separately from on board power
-Power ADC from GPIO pin

bschulz1701, 2018-04-10:
Fixed by creating an isolated on board I2C bus in addition to an external I2C bus, isolation was performed using the addition of a SN74LVC1G3157 SPDT analog switch. This issue was solved by the resolution of #7

bschulz1701, 2021-02-26:
Problem confirmed to be solved via addition of analog switch to separate `SDA_OB` and `SDA_EXT`

Note: this issue is being closed due to hardware functionality confirmed, need to resolve issue #24 in order to settle issue

Closed 2021-02-26.

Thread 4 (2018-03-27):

Flip I2C connector

bschulz1701, 2018-03-27:
Flip the I2C connector around, so that it matches with the Project Heptapod pinout

bschulz1701, 2018-05-04:
Fixed by flipping the connector. D'oh!

Closed 2018-05-04.

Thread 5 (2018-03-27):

Add Battery connector

bschulz1701, 2018-03-27:
Add JST battery connector to allow for more easy connection

bschulz1701, 2021-02-26:
After use case consideration, this feature has been put on indefinite hiatus

Closed 2021-02-26.

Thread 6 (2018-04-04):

Fix SD connection

bschulz1701, 2018-04-04:
Add hardware disconnect/isolation for SD card, either by use of N-FET on ground line of SD card, or through some kind of logic buffer

bschulz1701, 2018-05-04:
Fixed with addition of logic buffer

Closed 2018-05-04.

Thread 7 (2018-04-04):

Isolated I2C Bus

bschulz1701, 2018-04-04:
Add some kind of isolation to the I2C bus so that power is not drawn through the data lines of the I2C devices

bschulz1701, 2019-04-12:
Should be dealt with by using external pullups to `3V3_AUX` bus

bschulz1701, 2021-02-26:
Fixed by use of `3V3_AUX` as pullup source as opposed to `3V3`. This allows parasitic power to be eliminated to the fullest extent possible.

Note: This hardware fix allows for prevention of parasitic leakage, but it does not guarantee it. In order to ensure it does not occur, the I2C lines must be placed into the appropriate `INPUT` or `OUTPUT` - `LOW` condition during sleep state. Failure to do this, or placing lines in `INPUT_PULLUP` state, will result in parasitic leakage.

Closed 2021-02-26.

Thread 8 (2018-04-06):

Add I2C pullups

bschulz1701, 2018-04-06:

bschulz1701, 2018-04-10:
Fixed with addition of pull-ups (D'oh!)

bschulz1701, 2018-04-10:
Do we really need I2C pullups?

bschulz1701, 2018-07-18:
Add I2C pullups to the 3v3 External rail, this will fix startup problems and prevent lockups due to I2C after sleep, etc

Closed 2019-04-12.

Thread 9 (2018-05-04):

Use PG as cutoff

bschulz1701, 2018-05-04:
Use PG pin to connect to reset line (or some similar setup) to prevent writing to SD card when voltage is below cutoff (As this can cause corruption to files), alternative would be to use CRC check on SdFat writing

bschulz1701, 2021-02-26:
Currently `PG` is only provided as an input to the micro, it is reliant on the user to test `PG` via firmware before making writes to SD card in order to prevent corruption.

Note: The issue of SD cards being corrupted by voltages lower than 3.3V has been reported anecdotally, it has not been observed with the Margay system and can not be directly confirmed via SD card documentation. That being said, it is good idea to ensure power is stable and within operational ranges before making reads and writes regardless.

bschulz1701, 2021-09-08:
This could be implemented in hardware, but would require a fair bit of testing to make sure you don't get yourself into a corner on the power system (stuck in a reset loop, etc). This issue was added as the Cave Pearl group noted that you could corrupt the data on an SD card if you performed an undervoltage write (this is reasonable as if the voltage is not sufficient you may not be able to set the SRAM blocks, resulting in a check error). We have never seen this happen on any of our loggers, even when drained below the 3.3V + dropout (~175mV if I remember  correctly). Not to say it can't happen, which is why I put this issue as a long term want.
If you look at a micro SD card [datasheet](https://www.kingston.com/datasheets/SDCIT-specsheet-8gb-32gb_en.pdf), the supply voltage is rated down to 2.7V. The buffer we are using to communicate with the SD card (SN74AUP3G34, U5 on v2.2) is rated all the down to 0.8V. So in the dropout region (2.875V < Vin < 3.475V) the buffer should drive the SD card perfectly correctly and not provide a low voltage to the device. The micro is also able to work fine down to that voltage (discounting potential overclocking issues, but that is separate). All this to say that we have a pretty wide range after the device goes into dropout to detect low input voltage and stop logging before corruption occurs.
I think rather than trying to implement this in hardware (given the low likelihood of an issue and that it would take a bit of time better spent on more pressing issues) we should just implement it in firmware. Before writing to the SD card check the `PG` pin and do not write if it is low, instead print an error message or flash a low voltage light, etc. This should protect equally well against the issues and may be preferable, since it can give indication of the status rather than just being stuck in reset. I never love the idea of being dependent on mission critical elements in the firmware, but in this case, probably the better/simpler solution. Especially due to the fact we have not been contending with this problem. I have not yet tried to induce a corruption, but from inadvertent low voltage writes, it seems the voltage needs to very low (like 2.5V or less) to cause these kind of issues.

**tl;dr** - We have never observed this problem, this was a want. However, I think this would be better implemented in firmware for several reasons, would be a very simple implementation.

awickert, 2022-05-03:
Now that I have made some more significant changes towards v2.3, would you like to make these towards v3 of the board, such that this is the version that we will publish about?

Or should we keep things as they are and keep a possible hardware implementation (beyond `PG` being broken out) in the future / maybe won't happen?

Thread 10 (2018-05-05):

Add test for alarm pin in hardware test

bschulz1701, 2018-05-05:
Add a feature to test the hardware interrupt pin from the clock, do this by setting up an alarm on the clock, for 1 or 2 seconds, then wait and make sure interrupt gets triggered

bschulz1701, 2021-02-26:
This is a firmware issue and should be ported to the Margay_Library repo. This feature was added as of: 8afa026f7eff719172065aa3b60e5c7ad6d05fd9 (Merge branch 'master' into master, July 9th, 2018)

Recommend this issue be closed, can move to firmware repo for completeness

awickert, 2021-03-01:
Opened and closed an issue in the library repo here for completeness, per @bschulz1701:
https://github.com/NorthernWidget-Skunkworks/Margay_Library/issues/21
Now closing.

Closed 2021-03-01.

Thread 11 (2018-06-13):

Add 2nd analog channel?

bschulz1701, 2018-06-13:
Does it make sense to add a second analog channel for support of some sensor varieties?

bschulz1701, 2021-02-26:
Based on current use cases, we feel a focus on a robust digital interface makes more sense. Can be revisited later, but on extended hiatus.

awickert, 2021-03-01:
I will add "wontfix" and close. In practical use cases, it seems that an inexpensive external ADC breakout (e.g., https://www.adafruit.com/product/1085) is perfectly fine. Indeed, this ADC is well supported by the Adafruit Arduino library, https://github.com/adafruit/Adafruit_ADS1X15. Agree with @bschulz1701 that we could revisit this, but that with a quality I2C interface, we can easily expand the Margay without cramming more on board.

Closed 2021-03-01.

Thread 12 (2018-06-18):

Add BMP280 as on board sensor?

bschulz1701, 2018-06-18:
Add the Bosch BMP280 temp and pressure sensor to the board as an onboard sensor https://www.digikey.com/product-detail/en/bosch-sensortec/BMP280/828-1064-1-ND/6136315

Closed 2019-04-12.

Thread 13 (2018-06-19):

Fix power over USB issue

bschulz1701, 2018-06-19:
When powered over USB, on board power works fine, but external power floats at ~2.5v, which can cause some issues. When powered via battery, everything works fine.

Allow for some kind of bypass between 3.3v onboard to external for this case, or allow a bypass from USB input to battery input??

bschulz1701, 2021-02-26:
This feature was implemented in v0.2 by way of a power MUX to connect `VUSB` to `VMAIN` whenever `VUSB` is present, overriding the battery to preserve power when being supplied via USB. Se `U9` and `U10` in schematic for circuit details. This allows for smooth seamless switchover between supplies, as well as allowing the device to supplied solely via USB for bench top testing without needing to be concerned with batteries

Closed 2021-02-26.

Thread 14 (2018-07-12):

Fix button pad layout

bschulz1701, 2018-07-12:
Make sure button pad layout has been updated and fixed in Cold Silicon Library

[Datasheet](https://www.ckswitches.com/media/1476/pts810.pdf) to verify

bschulz1701, 2018-09-07:
Updated Cold Silicon to reflect proper layout, updated Margay board from there and fixed resulting routing errors

Closed 2018-09-07.

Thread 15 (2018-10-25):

Add Cap on backup battery

bschulz1701, 2018-10-25:
Add capacitor to backup battery to prevent debouncing and clock reset issues?

Closed 2019-04-12.

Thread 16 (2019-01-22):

Add pulldown resistor of `VSWITCH`

bschulz1701, 2019-01-22:
### Issue:
The output of `VSWITCH` can drive a load appropriately, but does not work well as a PWM output to a sensor or other device with high input impedance, since the bulk charge on the FET (Q1) is not dissipated.

### Solution:
Add a pulldown resistor to ground to drain this bulk capacitance after switching. Perform experimentation to determine best value. 1k is sufficient for even fast switching operations (<10us), but may be overly high for power consumption. Ensure result will work at switching frequencies > 100kHz (common PWM frequency)

bschulz1701, 2019-01-22:
### Additional Testing:
Testing revealed the bulk capacitance to be about 160nF, to get a clean square wave (rise + fall < 1%) for a 1kHz frequency (max standard Arduino PWM), need a **pulldown of < 24k&Omega;**
#### Updated Design:
For better performance, may be desirable to use a half bridge CMOS to drive the output

bschulz1701, 2019-01-22:
#### Updated Design:
This problem should be solved by use of MIC94090 load switch (slated to replace discrete mosfet design for v0.2). Use of **MIC94091** (fast turn on **with** output discharge feature), t_rise + t_delay = 0.8us, t_fall + t_delay = 70ns, so total transition time = 870ns, which would be appropriate for a switching signal of **>10kHz** for a <1% transition time.

bschulz1701, 2021-02-26:
The load switch with output discharge was implemented in v0.2 which allowed for push-pull driven outputs, resolving this problem.

Closed 2021-02-26.

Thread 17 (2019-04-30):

Leakage current into TPS2105 (v2 Only)

bschulz1701, 2019-04-30:
### Issue
When the system goes to sleep, the comparator (U4) inputs are both 0v, since the comparator has sufficient hysteresis the output stays set with the state of the last input combination. When the system is just powered over battery, this results in a high output (3.3v) which drives the select pin on the unpowered TPS2105, resulting in ~300nA of leakage current into the switch pin.

When the last power source is USB, the output state of the comparator is low (0v), which eliminates this leakage current.

### Potential Solution
Reconfigure the input/output scheme of the comparator/TPS2105

Switch the inputs on the comparator in order to satisfy the truth table:

| State | Output |
| ------------- | ------------- |
| V<sub>bat/2</sub> > V<sub>3v3FTDI</sub>  | 0 |
| V<sub>bat/2</sub> < V<sub>3v3FTDI</sub>   | 1  |

Then change the power switch device to be the TPS2104 instead of the TPS2105 since the TPS2104 has an inverted logic input, resulting in the same total equivalent logic between voltage input and voltage selected

bschulz1701, 2021-02-26:
Change was implemented in v2.2 (8ca38a50c7f0e3debad69798afdcdab926ccc984), confirmed successful on subsequent fab and testing. Issue can be closed, FIGHT FOR YOUR RIGHT TO ~~PARTY~~ HAVE OPTIMIZED POWER CONSUMPTION!

Closed 2021-02-26.

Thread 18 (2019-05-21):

USB Power Latch (Models < v2.1)

bschulz1701, 2019-05-21:
### Issue:
When USB power is connected while the battery is simultaneously connected, there is a small additional power draw due to voltage mismatches (~160uA @ 4.5v). This draw results in a latching of the USB power switch, such that when the USB is removed, the FTDI draws power parasitically from the battery (~400uA @ 4.5v), this problem persists even in sleep mode and power down.

### Workaround:
If the USB is desired to be connected while battery is also connected (to check battery voltage, system status, etc), it is recommended to minimize this time simply to reduce draw on the battery. Then, once the USB is removed, make sure to **power cycle the battery**, this will fix the latching problem.

#### Updates:
The latching problem has been fixed on models >= `v2.1`, so no power cycle is required. However, the small current draw due to voltage mismatch is still present, so it is still recommended to reduce the time both are connected, simply to preserve the battery charge.

awickert, 2021-03-01:
Closing per @bschulz1701: This has been resolved on newer versions, so the general problem has been solved. This will stay as an archive for those concerned about power draw in prior versions.

Closed 2021-03-01.

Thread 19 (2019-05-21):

Reverse Polarity with USB (Model v0.0)

bschulz1701, 2019-05-21:
### Issue:
When USB power is applied **and** the battery is reverse polarized **destructive heating can occur**.

This issue occurs only when (reverse polarity) battery power is applied, followed by USB power. When this occurs, power is dissipated across `Q2` (the reverse polarity protection diode), causing significant heating.

#### Testing:
The following tests were performed in order to characterize the performance of the reverse current protection
**Test 1:**
USB power applied, **then** reverse polarity battery voltage applied
V<sub>Bat</sub> = 4.5v (power supply)
V<sub>USB</sub> = 5v (power supply)
T<sub>Ambient</sub> = 25&deg;C

| Time [s] | I<sub>Bat</sub> [mA] | T<sub>Q2</sub> [&deg;C] |
| --------  | -------------------------- | ------------------------------  |
| 0 | 16.3 | 25 |
| 15 | 16.3 | 30 |
| 30 | 16.3 | 32 |
| 120 | 16.3 | 35* |

*Stabilized temp

Note: These results are the same for all power cycling conditions for Model > v0.0

**Test 2:**
Reverse battery power applied, **then** USB voltage applied
V<sub>Bat</sub> = 4.5v (power supply)
V<sub>USB</sub> = 5v (power supply)
T<sub>Ambient</sub> = 25&deg;C

| Time [s] | I<sub>Bat</sub> [mA] | T<sub>Q2</sub> [&deg;C] |
| --------  | -------------------------- | ------------------------------  |
| 0 | 16.3 | 25 |
| 5 | 110 | 35 |
| 15 | 126 | 67 |
| 30 | 130 | 85 |
| 60 | 130 | 100 |

### Workaround:
For these older models, it is recommended to connect the battery power with **USB disconnected**, then verify by the presence of status lights that the logger is properly powered. Once this is verified, it is then safe to connect USB in parallel as usual.

awickert, 2021-03-01:
v0.0 is long superceded; closing per @bschulz1701 and leaving this as a warning for anyone using our few pieces of earliest hardware. (Currently just us and two collaborators.)

Closed 2021-03-01.

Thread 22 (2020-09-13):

Installation formatting

morandagny, 2020-09-13:
Installation section needs to be expanded beyond just the current "software" section/created and formatted similar to Resnik/Haar/etc. for consistency/readability/approachability. Also should be sure that during the creation of this installation section if anything is found to be wrong/out of date/buggy to fix that in corresponding areas in other datalogger installation sections. Will double check and make documentation issues on those pages if found.

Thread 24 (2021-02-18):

Off-board I2C nonfunctional

awickert, 2021-02-18:
From conversations with @bschulz1701, I recall this to be an issue in firmware rather than in hardware.

In order for communications to work with any off-board I2C device, we currently are required to solder across the on/off-board I2C jumper on the back (SD card side) of the Margay. We should (a) as a stop-gap, default to solder-jumpering these, and/or in the longer term (b) fix the firmware.

awickert, 2021-02-25:
If this is to remain this way for some time, also consider including this as a note in the documentation update.

awickert, 2021-03-01:
I just opened https://github.com/NorthernWidget-Skunkworks/Margay_Library/issues/22 to reference this from the firmware library. If it turns out to be a firmware issue, we can close this one and move discussion there.

Closed 2021-03-02.

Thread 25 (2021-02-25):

Is soldering J1 to 3v3 (or perhaps Vbat) to set the voltage of Vs required?

awickert, 2021-02-25:
@jbcannon noted in email that on his boards' builds (produced through PCBWay):

"The SD card detection issue appears fixed with this J1 pad jumper (without me having to circumvent the SD card check)... and the function of the Reset button when running on battery is now restored."

@jbcannon was having issues with the reset button when running the "benchtop" sketch (i.e., not sleeping) and with SD card writing when running the standard Margay programs (with sleeping).

Here's the question. Is this an issue with leaving a pin on the [MIC94094YC6-TR](https://www.digikey.com/en/products/detail/microchip-technology/MIC94094YC6-TR/2062452) floating? Or is this some sort of fix that perhaps clamps down a voltage on shoddy hardware and keeps the ship held together? And even if the latter, is it best practice to always select one of these solder-jumper options, in which case we should perhaps include that in the solder stencil Gerber?

awickert, 2021-02-25:
Talking with @bschulz1701 right now.

Yes, it is best to not keep this pin floating, though there is nothing in particular that should cause an issue. @awickert has a Margay built by Caltronics where this is disconnected, but it isn't a problem. But we shouldn't have ill-defined states.

Indeed we do have Vcream already set up to link this to the battery power, so this shouldn't have been disconnected:
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

More generally, there might have been a problem in fab because of the surface tension at the corners of the rectangular pads. **We should switch these on the Margay board to rounded-edge pads (semicircular ones).**

Whe making this change, let's **switch default to 3V3** so the full system is defaulting to the same voltage.

awickert, 2021-03-01:
I have made the change to a 3V3 default connection and have pushed it. The `Vswitch` pin will now default its connection to `3V3_AUX` via the stenciled-on solder-paste jumper.

Revision here: f548f917aa99fd3005058ddd31e623f4deecff98

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

Closed 2021-03-01.

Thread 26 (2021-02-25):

CR1220 required for logger to wake up

awickert, 2021-02-25:
This is the clock battery. Based on comments from @jbcannon, we should make it really clear to users that the logger won't be able to wake up unless the clock (RTC) is powered. This is especially true because users may not even realize that it is the RTC that the CR1220 powers. More documentation is better!

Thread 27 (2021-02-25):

Verify clock-fail error code

awickert, 2021-02-25:
Take the CR1220 out of a Margay. Start it up. Does it:
* Give the proper LED blink code (Cyan blinking)
* Print to serial that it has a clock fail (CLOCK: ERROR)
?

awickert, 2021-03-01:
Note: Close and reopen at firmware library in case this is more a firmware issue.
https://github.com/NorthernWidget-Skunkworks/Margay_Library

Closed 2021-03-02.

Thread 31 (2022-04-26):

Unable to access external ADC while using Margay::run()

ericbarefoot, 2022-04-26:
`Margay:run()` does not permit the user to access the on-board (but also external) ADC. This component is needed to read analog voltages, but cannot be accessed if one is also reading data from an external I2C unit.

Closed 2022-04-26.

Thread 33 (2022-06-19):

Update Xtal (Obsolete)

awickert, 2022-06-19:
8MHz crystal no longer produced:
https://www.digikey.com/en/products/detail/txc-corporation/7A-8-000MAHJ-T/6130668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

Update on board and BoM

Look into any needed changes in decoupling caps, too.

awickert, 2022-10-05:
Digi-Key indicates that this piece is a drop-in replacement (using their new/ish? "myLists" feature) and my first looks confirm this.

https://www.digikey.com/en/products/detail/ecs-inc/ECS-80-12-30-JGM-TR/13968095

Second eyes would be good. Perhaps best to update this part definition in https://github.com/bschulz1701/Cold-Silicon

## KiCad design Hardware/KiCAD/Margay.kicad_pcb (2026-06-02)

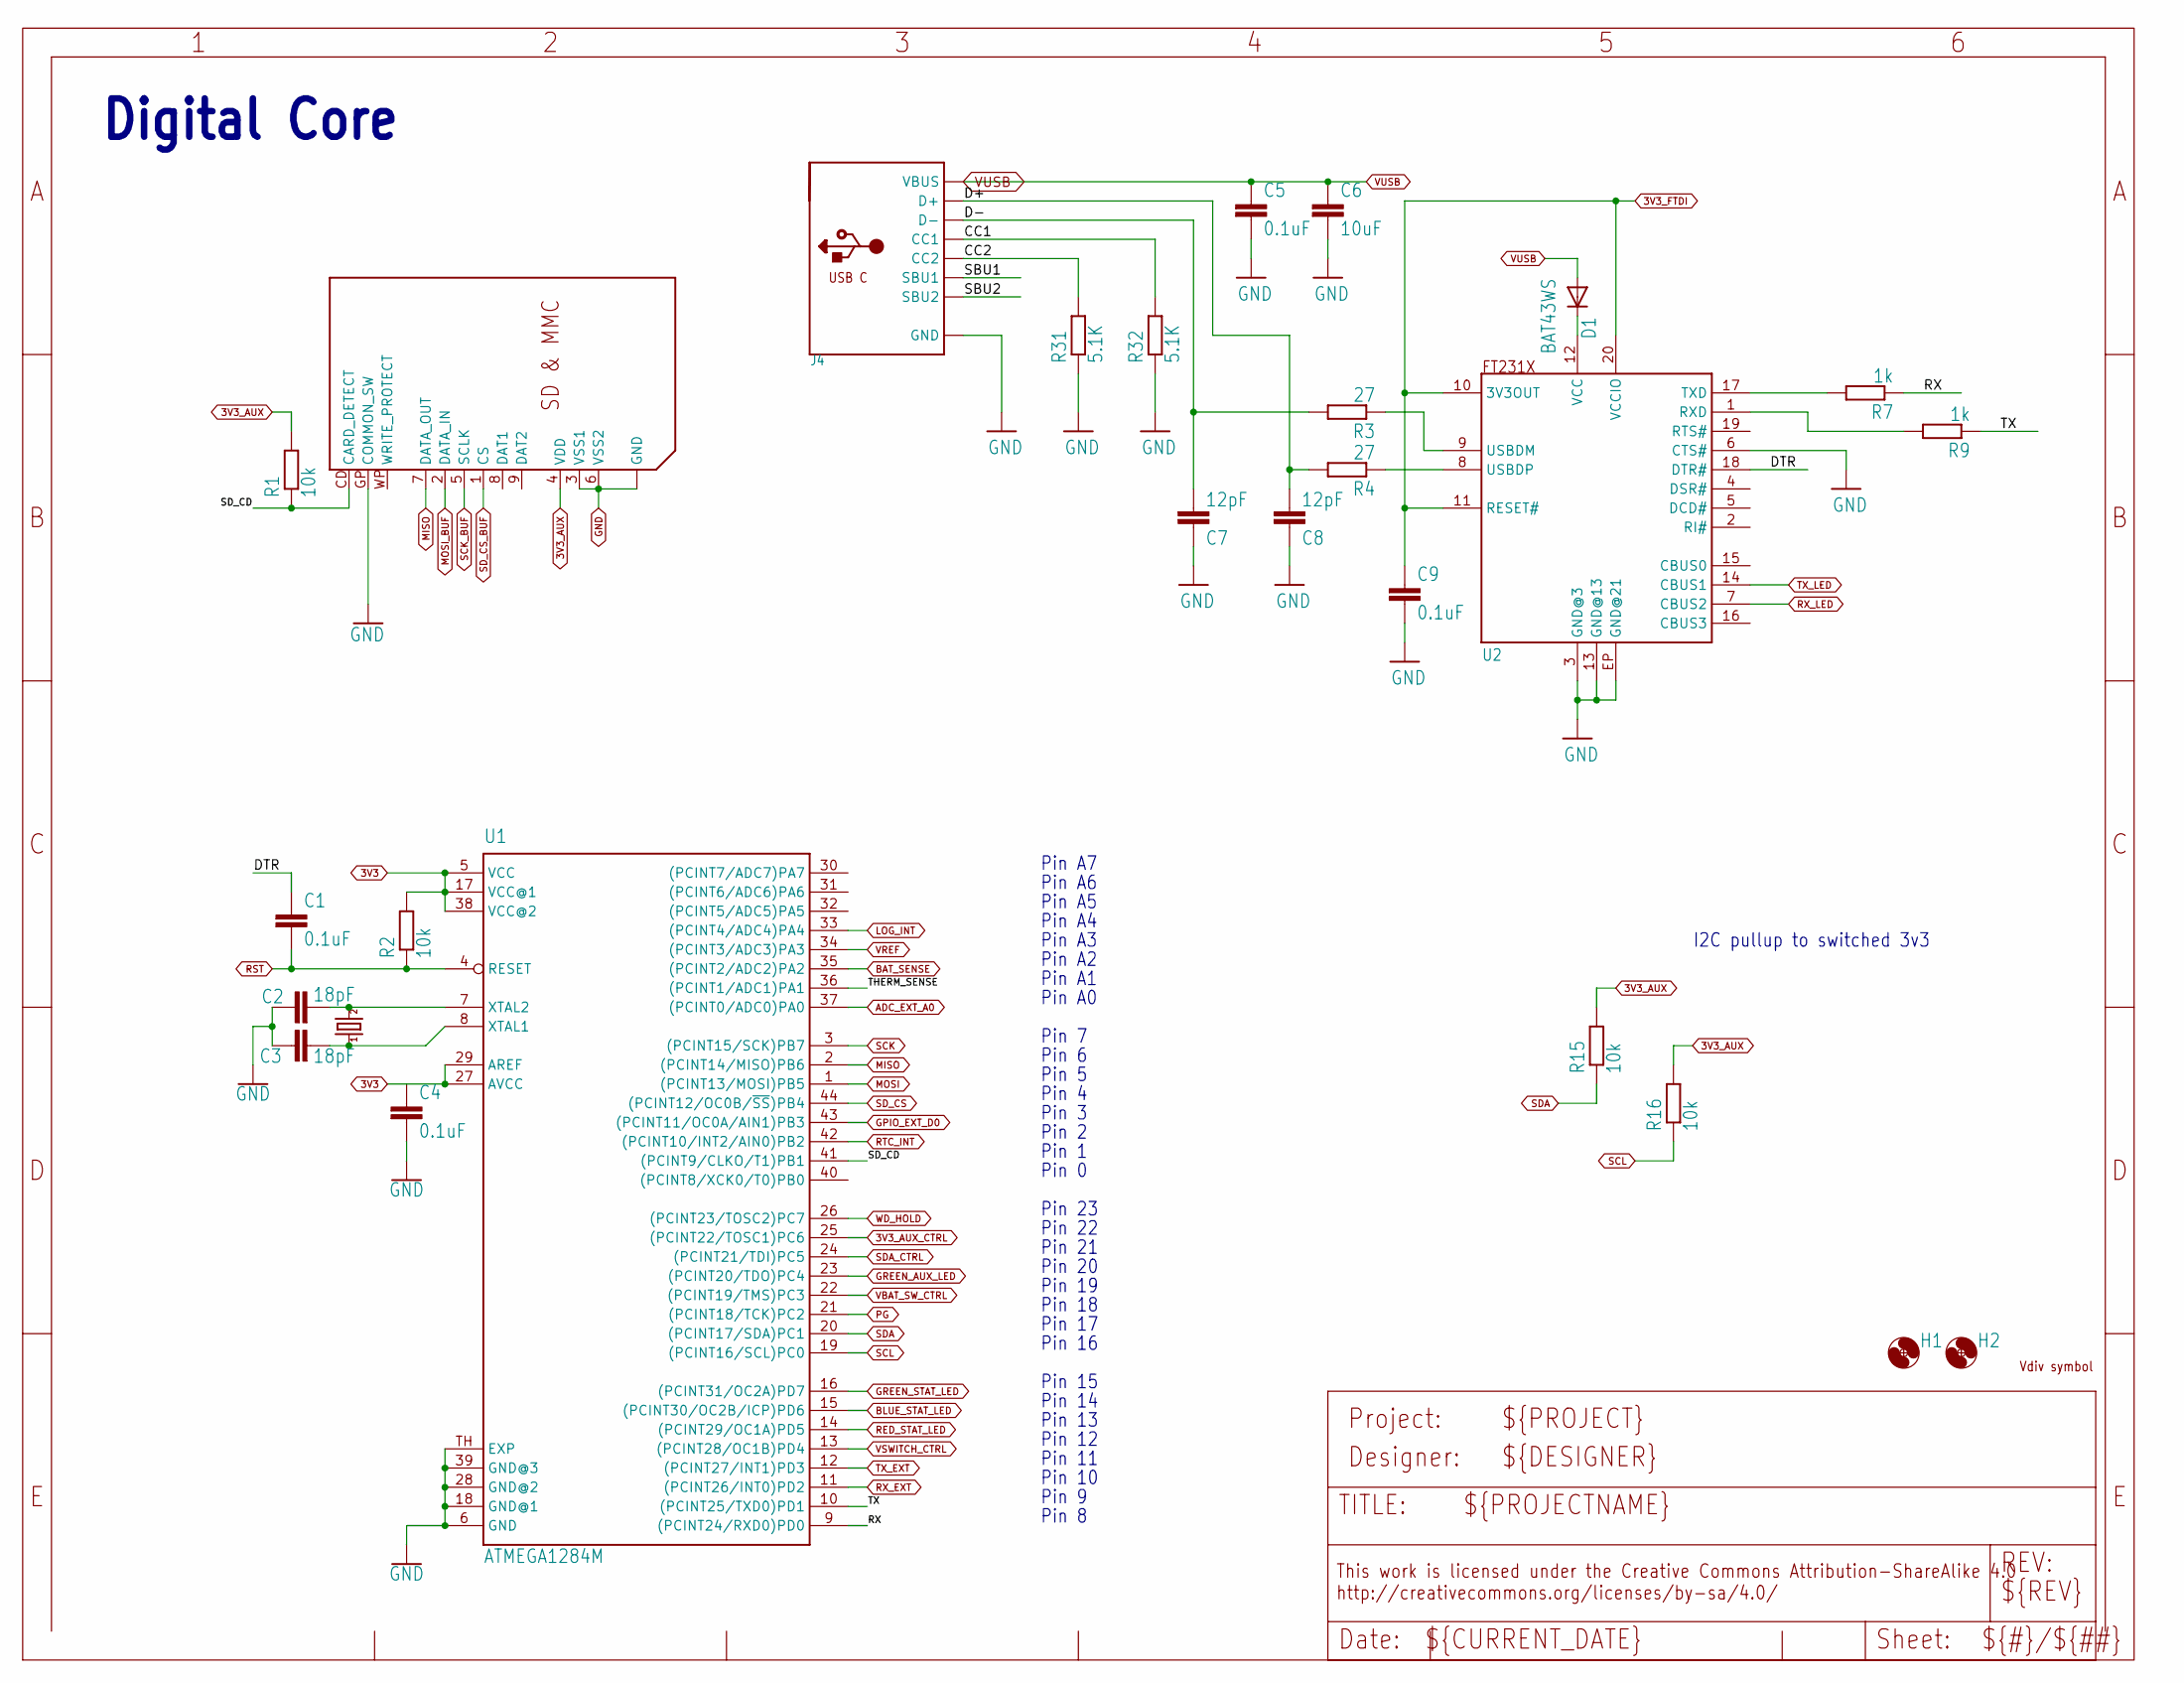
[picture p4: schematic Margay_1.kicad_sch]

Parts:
C1, C4, C5, C9: 0.1uF; C0402; MPN GCM155R71C104KA55D; DIGIKEY 490-4759-1-ND
C2, C3: 18pF; C0402; MPN GCM1555C1H180JA16D; DIGIKEY 490-12650-1-ND
C6: 10uF; C0805; MPN GRM21BR61C106KE15K; DIGIKEY 490-6473-1-ND
C7, C8: 12pF; C0402; MPN CGA2B2C0G1H120J050BA; DIGIKEY 445-5585-1-ND
D1: BAT43WS; SOD323-R; MPN BAT43WS-7-F; DIGIKEY BAT43WS-FDICT-ND
H1, H2: MOUNTING_HOLE4_NP_CLOSE; 4_40_CLOSE; MPN N/A; DIGIKEY DNP
J1: SDMMCWR-CRD; SD_WURTH_WR-CRD; MPN 693063010911; DIGIKEY 732-3817-1-ND
J4: USB_C; USB_C_CUSB31-CFM2AX-01-X; MPN USB4105-GF-A; DIGIKEY 2073-USB4105-GF-ACT-ND
R1, R2, R15, R16: 10k; R0402; MPN RC0402FR-0710KL; DIGIKEY 311-10.0KLRCT-ND
R3, R4: 27; R0402; MPN RC0402FR-0727RL; DIGIKEY YAG3086CT-ND
R7, R9: 1k; R0402; MPN RC0402FR-071KL
R31, R32: 5.1K; R0402; MPN RC0402FR-075K1L; DIGIKEY 311-5.10KLRCT-ND
U1: ATMEGA1284M; MLF44-TH; MPN ATMEGA1284P-MUR; DIGIKEY ATMEGA1284P-MURCT-ND
U2: FT231X-Q; QFN20; MPN FT231XQ-R; DIGIKEY 768-1128-1-ND
U$1: VDIV_MARGAYFULL-VDIV; VDIV_MARGAY_2021; MPN N/A; DIGIKEY DNP
XTAL1: CRYSTAL5X3.2; CRYSTAL_5X3.2_2-SMD; MPN ECS-80-18-30-JGN-TR; DIGIKEY XC2103CT-ND

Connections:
3V3: C4.1, R2.2, U1.5 (VCC), U1.17 (VCC@1), U1.27 (AVCC), U1.29 (AREF), U1.38 (VCC@2); also elsewhere on the board
3V3_AUX: J1.4 (VDD), R1.2, R15.2, R16.2; also elsewhere on the board
3V3_AUX_CTRL: U1.25 ((PCINT22/TOSC1)PC6); also elsewhere on the board
3V3_FTDI: C9.1, U2.10 (3V3OUT), U2.11 (RESET#), U2.20 (VCCIO); also elsewhere on the board
/Margay_1/CC1: J4.A5 (CC1), R32.2
/Margay_1/CC2: J4.B5 (CC2), R31.2
/Margay_1/D+: C8.2, J4.A6 (D+), J4.B6 (D+), R4.2
/Margay_1/D-: C7.2, J4.A7 (D-), J4.B7 (D-), R3.2
/Margay_1/DTR: C1.1, U2.18 (DTR#)
/Margay_1/RX: R7.1, U1.9 ((PCINT24/RXD0)PD0)
/Margay_1/SBU1: J4.A8 (SBU1)
/Margay_1/SBU2: J4.B8 (SBU2)
/Margay_1/SD_CD: J1.CD (CARD_DETECT), R1.1, U1.41 ((PCINT9/CLKO/T1)PB1)
/Margay_1/THERM_SENSE: U1.36 ((PCINT1/ADC1)PA1)
/Margay_1/TX: R9.1, U1.10 ((PCINT25/TXD0)PD1)
ADC_EXT_A0: U1.37 ((PCINT0/ADC0)PA0); also elsewhere on the board
BAT_SENSE: U1.35 ((PCINT2/ADC2)PA2); also elsewhere on the board
BLUE_STAT_LED: U1.15 ((PCINT30/OC2B/ICP)PD6); also elsewhere on the board
GND: C2.1, C3.1, C4.2, C5.2, C6.2, C7.1, C8.1, C9.2, J1.3 (VSS1), J1.6 (VSS2), J1.GP (COMMON_SW), J1.GP2 (GND), J1.GP3 (GND), J1.GP4 (GND), J4.A1B12 (GND), J4.B1A12 (GND), R31.1, R32.1, U1.6 (GND), U1.18 (GND@1), U1.28 (GND@2), U1.39 (GND@3), U1.TH (EXP), U2.3 (GND@3), U2.6 (CTS#), U2.13 (GND@13), U2.EP (GND@21); also elsewhere on the board
GPIO_EXT_D0: U1.43 ((PCINT11/OC0A/AIN1)PB3); also elsewhere on the board
GREEN_AUX_LED: U1.23 ((PCINT20/TDO)PC4); also elsewhere on the board
GREEN_STAT_LED: U1.16 ((PCINT31/OC2A)PD7); also elsewhere on the board
LOG_INT: U1.33 ((PCINT4/ADC4)PA4); also elsewhere on the board
MISO: J1.7 (DATA_OUT), U1.2 ((PCINT14/MISO)PB6); also elsewhere on the board
MOSI: U1.1 ((PCINT13/MOSI)PB5); also elsewhere on the board
MOSI_BUF: J1.2 (DATA_IN); also elsewhere on the board
unnamed: C3.2, U1.8 (XTAL1), XTAL1.OSC1 (1)
unnamed: C2.2, U1.7 (XTAL2), XTAL1.OSC2 (2)
unnamed: R9.2, U2.1 (RXD)
unnamed: R7.2, U2.17 (TXD)
unnamed: R3.1, U2.9 (USBDM)
unnamed: R4.1, U2.8 (USBDP)
unnamed: D1.C, U2.12 (VCC)
PG: U1.21 ((PCINT18/TCK)PC2); also elsewhere on the board
RED_STAT_LED: U1.14 ((PCINT29/OC1A)PD5); also elsewhere on the board
RST: C1.2, R2.1, U1.4 (RESET); also elsewhere on the board
RTC_INT: U1.42 ((PCINT10/INT2/AIN0)PB2); also elsewhere on the board
RX_EXT: U1.11 ((PCINT26/INT0)PD2); also elsewhere on the board
RX_LED: U2.7 (CBUS2); also elsewhere on the board
SCK: U1.3 ((PCINT15/SCK)PB7); also elsewhere on the board
SCK_BUF: J1.5 (SCLK); also elsewhere on the board
SCL: R16.1, U1.19 ((PCINT16/SCL)PC0); also elsewhere on the board
SDA: R15.1, U1.20 ((PCINT17/SDA)PC1); also elsewhere on the board
SDA_CTRL: U1.24 ((PCINT21/TDI)PC5); also elsewhere on the board
SD_CS: U1.44 ((PCINT12/OC0B/~SS)PB4); also elsewhere on the board
SD_CS_BUF: J1.1 (CS); also elsewhere on the board
TX_EXT: U1.12 ((PCINT27/INT1)PD3); also elsewhere on the board
TX_LED: U2.14 (CBUS1); also elsewhere on the board
VBAT_SW_CTRL: U1.22 ((PCINT19/TMS)PC3); also elsewhere on the board
VREF: U1.34 ((PCINT3/ADC3)PA3); also elsewhere on the board
VSWITCH_CTRL: U1.13 ((PCINT28/OC1B)PD4); also elsewhere on the board
VUSB: C5.1, C6.1, D1.A, J4.A4B9 (VBUS), J4.B4A9 (VBUS); also elsewhere on the board
WD_HOLD: U1.26 ((PCINT23/TOSC2)PC7); also elsewhere on the board

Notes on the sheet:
Pin A2
Pin 13
Pin 23
Pin A7
Pin 20
Pin 6
Pin 16
Pin 17
Pin 5
Pin 12
Pin 14
Pin 9
Pin 0
Pin 4
Pin 10
Pin 22
Pin 8
Pin A6
Pin 7
Pin A4
Pin 15
Digital Core
Pin 3
Pin A1
Pin 18
Pin A0
Pin 19
Pin 1
Pin 21
I2C pullup to switched 3v3
Pin A3
Pin A5
Pin 11
Pin 2

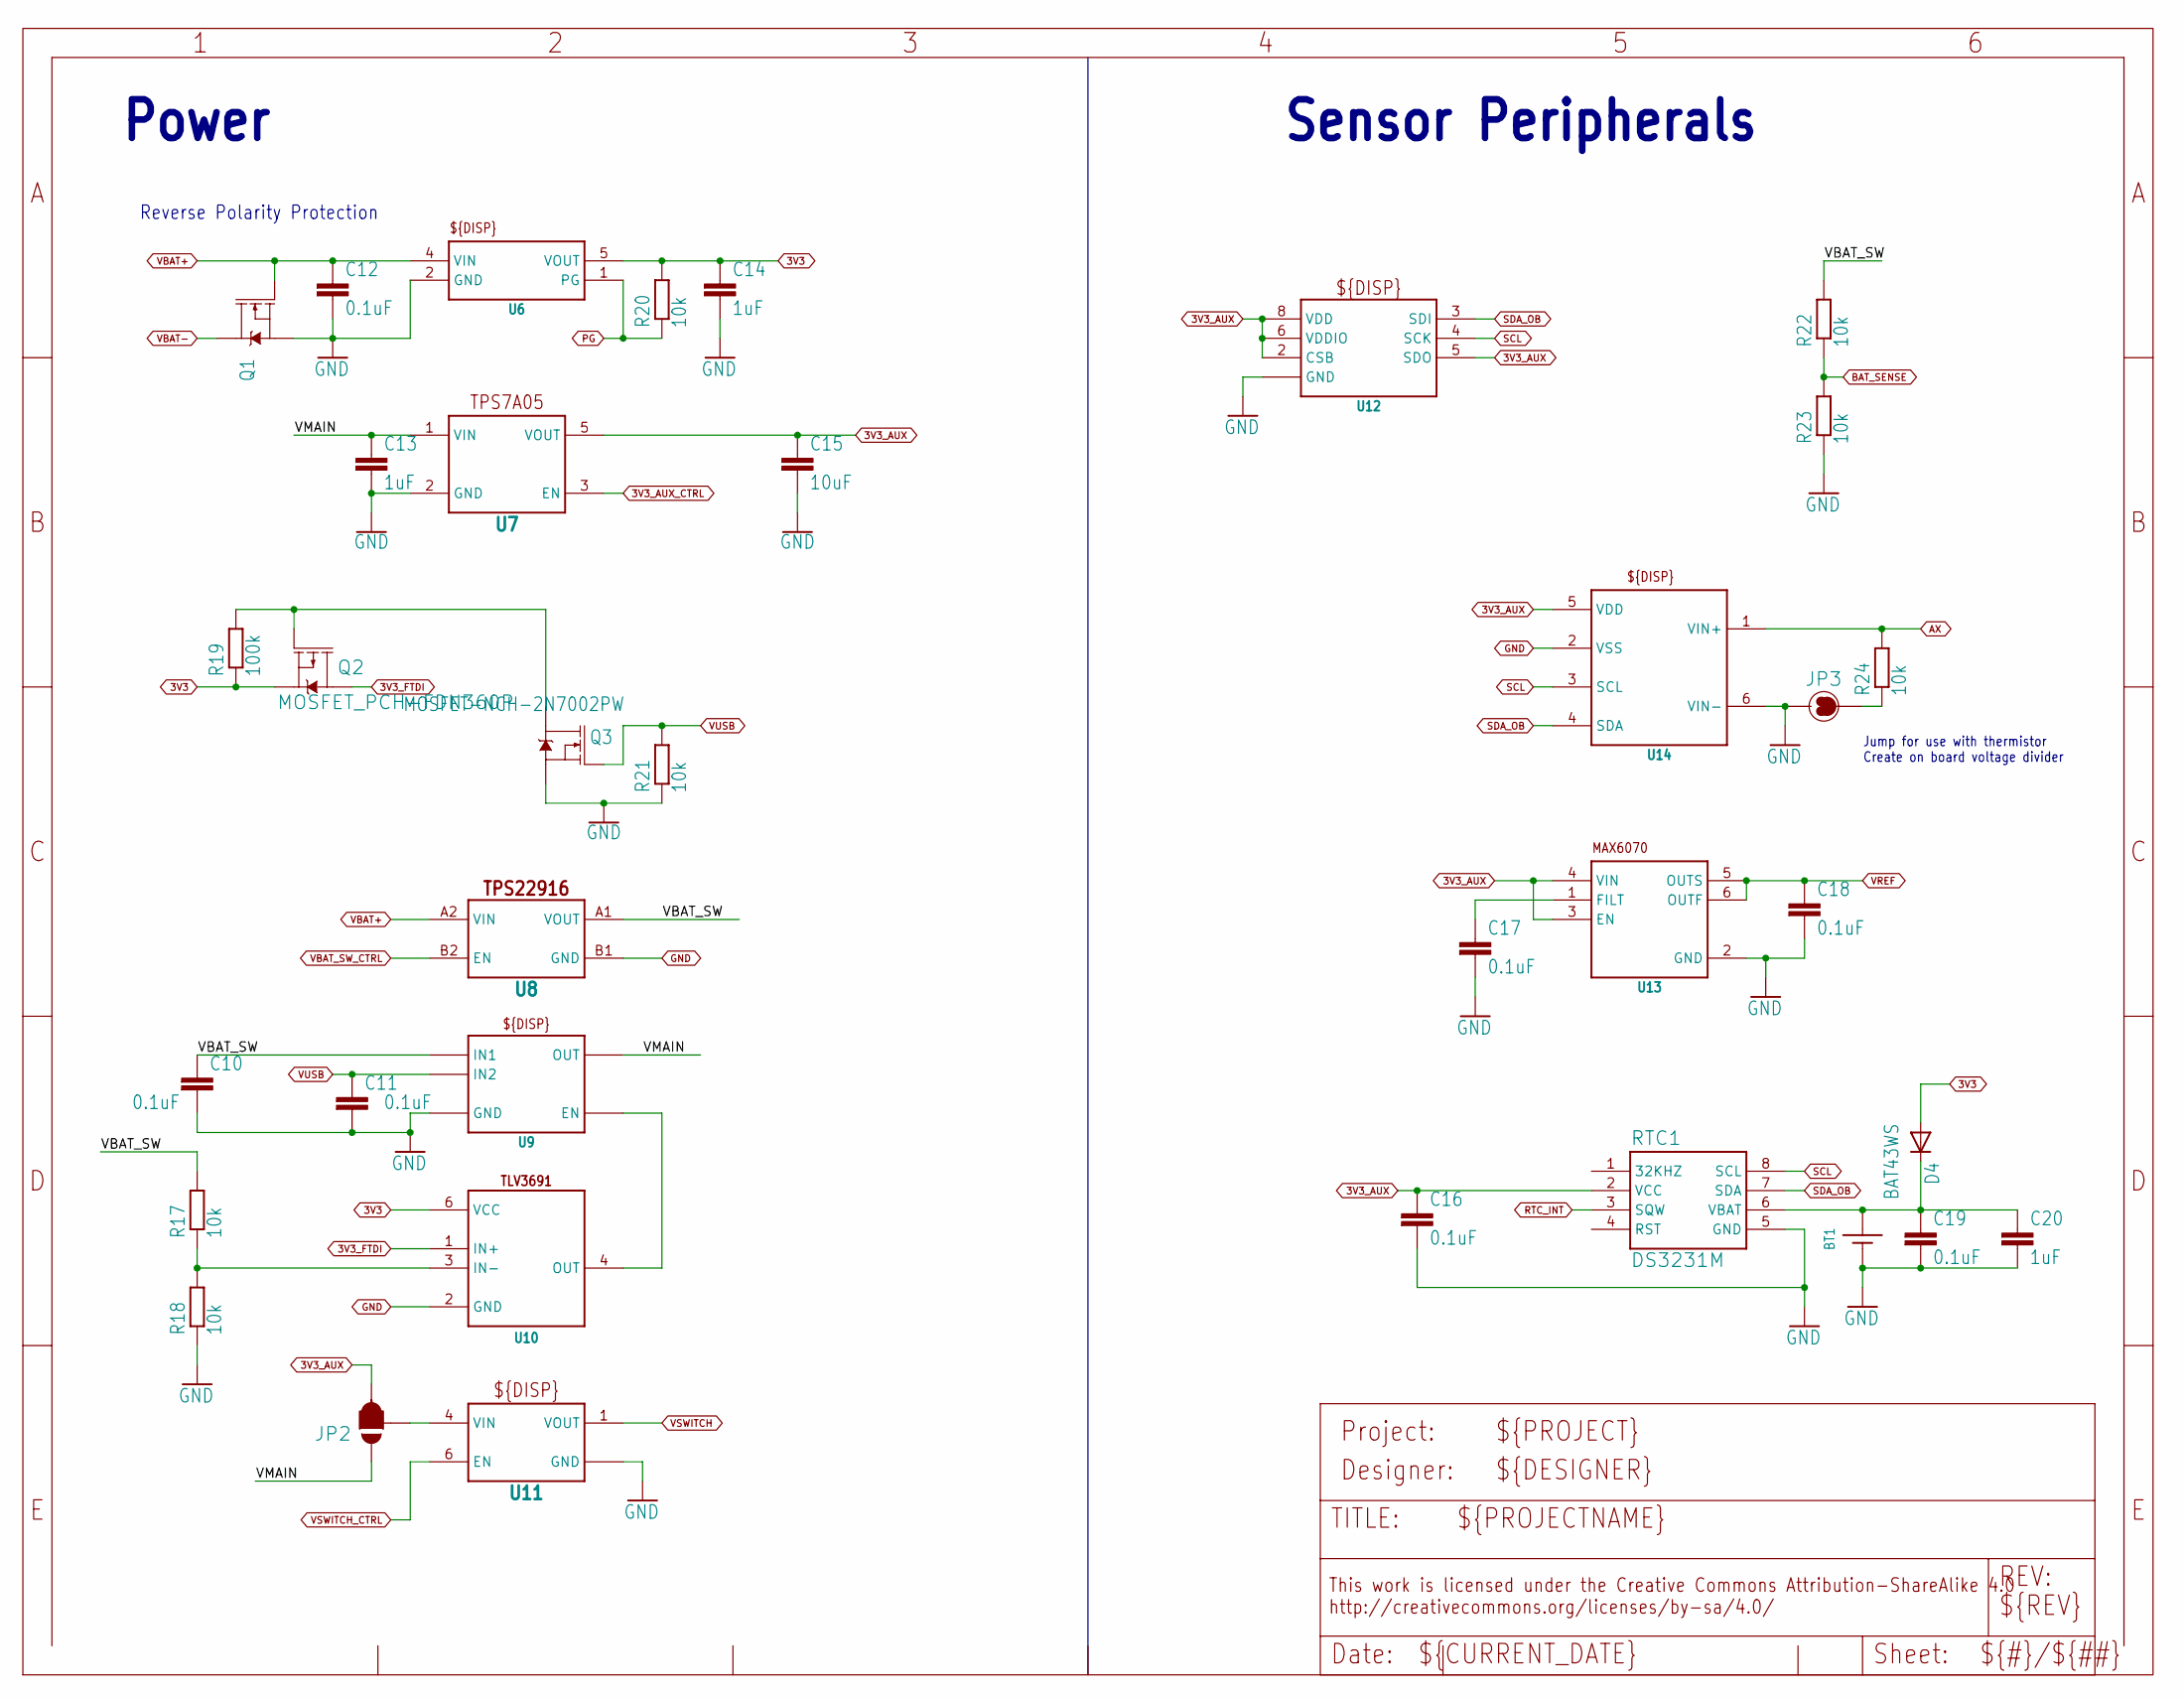
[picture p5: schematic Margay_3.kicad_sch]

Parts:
BT1: BATTERY_COIN12MM; LINX_BAT-HLD-012-SMT; MPN BAT-HLD-012-SMT; DIGIKEY BAT-HLD-012-SMT-ND
C10, C11, C12, C16, C17, C18, C19: 0.1uF; C0402; MPN GCM155R71C104KA55D; DIGIKEY 490-4759-1-ND
C13, C14, C20: 1uF; C0603; MPN TMK107B7105KA-T; DIGIKEY 587-2984-1-ND
C15: 10uF; C0805; MPN GRM21BR61C106KE15K; DIGIKEY 490-6473-1-ND
D4: BAT43WS; SOD323-R; MPN BAT43WS-7-F; DIGIKEY BAT43WS-FDICT-ND
JP2: JUMPER-SMT_3_1-NC_PASTE_SILK; SMT-JUMPER_3_1-NC_PASTE_SILK; MPN N/A; DIGIKEY DNP
JP3: JUMPER-SMT_2_NC_PASTE_SILK; SMT-JUMPER_2_NC_PASTE_SILK; MPN N/A; DIGIKEY DNP
Q1: MOSFET-NCH-DMG3404L; SOT23-3; MPN DMG3404L-7; DIGIKEY DMG3404L-7DICT-ND
Q2: MOSFET_PCH-FDN360P; SOT23-3@1; MPN DMP3099L-7; DIGIKEY DMP3099L-7DICT-ND
Q3: MOSFET-NCH-2N7002PW; SOT323; MPN 2N7002W-7-F; DIGIKEY 2N7002W-FDICT-ND
R17, R18, R20, R21: 10k; R0402; MPN RC0402FR-0710KL; DIGIKEY 311-10.0KLRCT-ND
R19: 100k; R0402; MPN RC0402FR-07100RL; DIGIKEY 311-100LRCT-ND
R22, R24: 10k; R0603; MPN CRT0603-BY-1002ELF; DIGIKEY CRT0603-BY-1002ELFCT-ND
R23: 10k; R0603; MPN CRT0603-BY-1002ELFCT-ND; DIGIKEY CRT0603-BY-1002ELFCT-ND
RTC1: DS3231M; SO08; MPN DS3231MZ+; DIGIKEY DS3231MZ+-ND
U6: TPS797; DCK_R-PDSO-G5; MPN TPS79733DCKR; DIGIKEY 296-11990-1-ND
U7: TPS7A05DBV; SOT23-5; MPN TPS7A0533PDBVR; DIGIKEY 296-50256-1-ND
U8: TPS22916YFP; YFP0004; MPN TPS22916CYFPT; DIGIKEY 296-47464-1-ND
U9: TPS210; SOT23-5; MPN TPS2104DBVT; DIGIKEY 296-TPS2104DBVTCT-ND
U10: TLV3691DPF; DPF0006A; MPN TLV3691IDPFR; DIGIKEY 296-37242-6-ND
U11: MIC9409C6; SC-70_6; MPN MIC94090YC6-TR; DIGIKEY 576-3484-1-ND
U12: BME280; MPN BME280; DIGIKEY 828-1063-1-ND
U13: MAX6070AAUT; SOT23-6L; MPN MAX6070BAUT18+T; DIGIKEY MAX6070BAUT18+TCT-ND
U14: MCP342; SOT23-6L; MPN MCP3421A1T-E/CH; DIGIKEY MCP3421A1T-E/CHCT-ND

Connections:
3V3: C14.1, D4.A, Q2.2 (S), R19.1, R20.2, U6.5 (VOUT), U10.6 (VCC); also elsewhere on the board
3V3_AUX: C15.1, C16.1, JP2.3, RTC1.2 (VCC), U7.5 (VOUT), U12.2 (CSB), U12.5 (SDO), U12.6 (VDDIO), U12.8 (VDD), U13.3 (EN), U13.4 (VIN), U14.5 (VDD); also elsewhere on the board
3V3_AUX_CTRL: U7.3 (EN); also elsewhere on the board
3V3_FTDI: Q2.3 (D), U10.1 (IN+); also elsewhere on the board
/Margay_3/VBAT_SW: C10.1, R17.2, R22.2, U8.A1 (VOUT), U9.5 (IN1)
/Margay_3/VMAIN: C13.1, JP2.1, U7.1 (VIN), U9.4 (OUT)
AX: R24.2, U14.1 (VIN+); also elsewhere on the board
BAT_SENSE: R22.1, R23.2; also elsewhere on the board
GND: BT1.GND (-), C10.2, C11.2, C12.2, C13.2, C14.2, C15.2, C16.2, C17.2, C18.2, C19.2, C20.2, JP3.1, Q1.2 (S), Q3.2 (S), R18.1, R21.1, R23.1, RTC1.5 (GND), U6.2 (GND), U7.2 (GND), U8.B1 (GND), U9.2 (GND), U10.2 (GND), U11.2 (GND), U11.5 (GND), U12.1 (GND), U12.7 (GND), U13.2 (GND), U14.2 (VSS), U14.6 (VIN-); also elsewhere on the board
unnamed: JP3.2, R24.1
unnamed: Q2.1 (G), Q3.3 (D), R19.2
unnamed: BT1.POWER0 (+), BT1.POWER1 (+), C19.1, C20.1, D4.C, RTC1.6 (VBAT)
unnamed: R17.1, R18.2, U10.3 (IN-)
unnamed: U9.1 (EN), U10.4 (OUT)
unnamed: JP2.2, U11.4 (VIN)
unnamed: C17.1, U13.1 (FILT)
PG: R20.1, U6.1 (PG); also elsewhere on the board
RTC_INT: RTC1.3 (SQW); also elsewhere on the board
SCL: RTC1.8 (SCL), U12.4 (SCK), U14.3 (SCL); also elsewhere on the board
SDA_OB: RTC1.7 (SDA), U12.3 (SDI), U14.4 (SDA); also elsewhere on the board
VBAT+: C12.1, Q1.1 (G), U6.4 (VIN), U8.A2 (VIN); also elsewhere on the board
VBAT-: Q1.3 (D); also elsewhere on the board
VBAT_SW_CTRL: U8.B2 (EN); also elsewhere on the board
VREF: C18.1, U13.5 (OUTS), U13.6 (OUTF); also elsewhere on the board
VSWITCH: U11.1 (VOUT); also elsewhere on the board
VSWITCH_CTRL: U11.6 (EN); also elsewhere on the board
VUSB: C11.1, Q3.1 (G), R21.2, U9.3 (IN2); also elsewhere on the board

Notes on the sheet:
Jump for use with thermistor Create on board voltage divider
Power
Reverse Polarity Protection
Sensor Peripherals

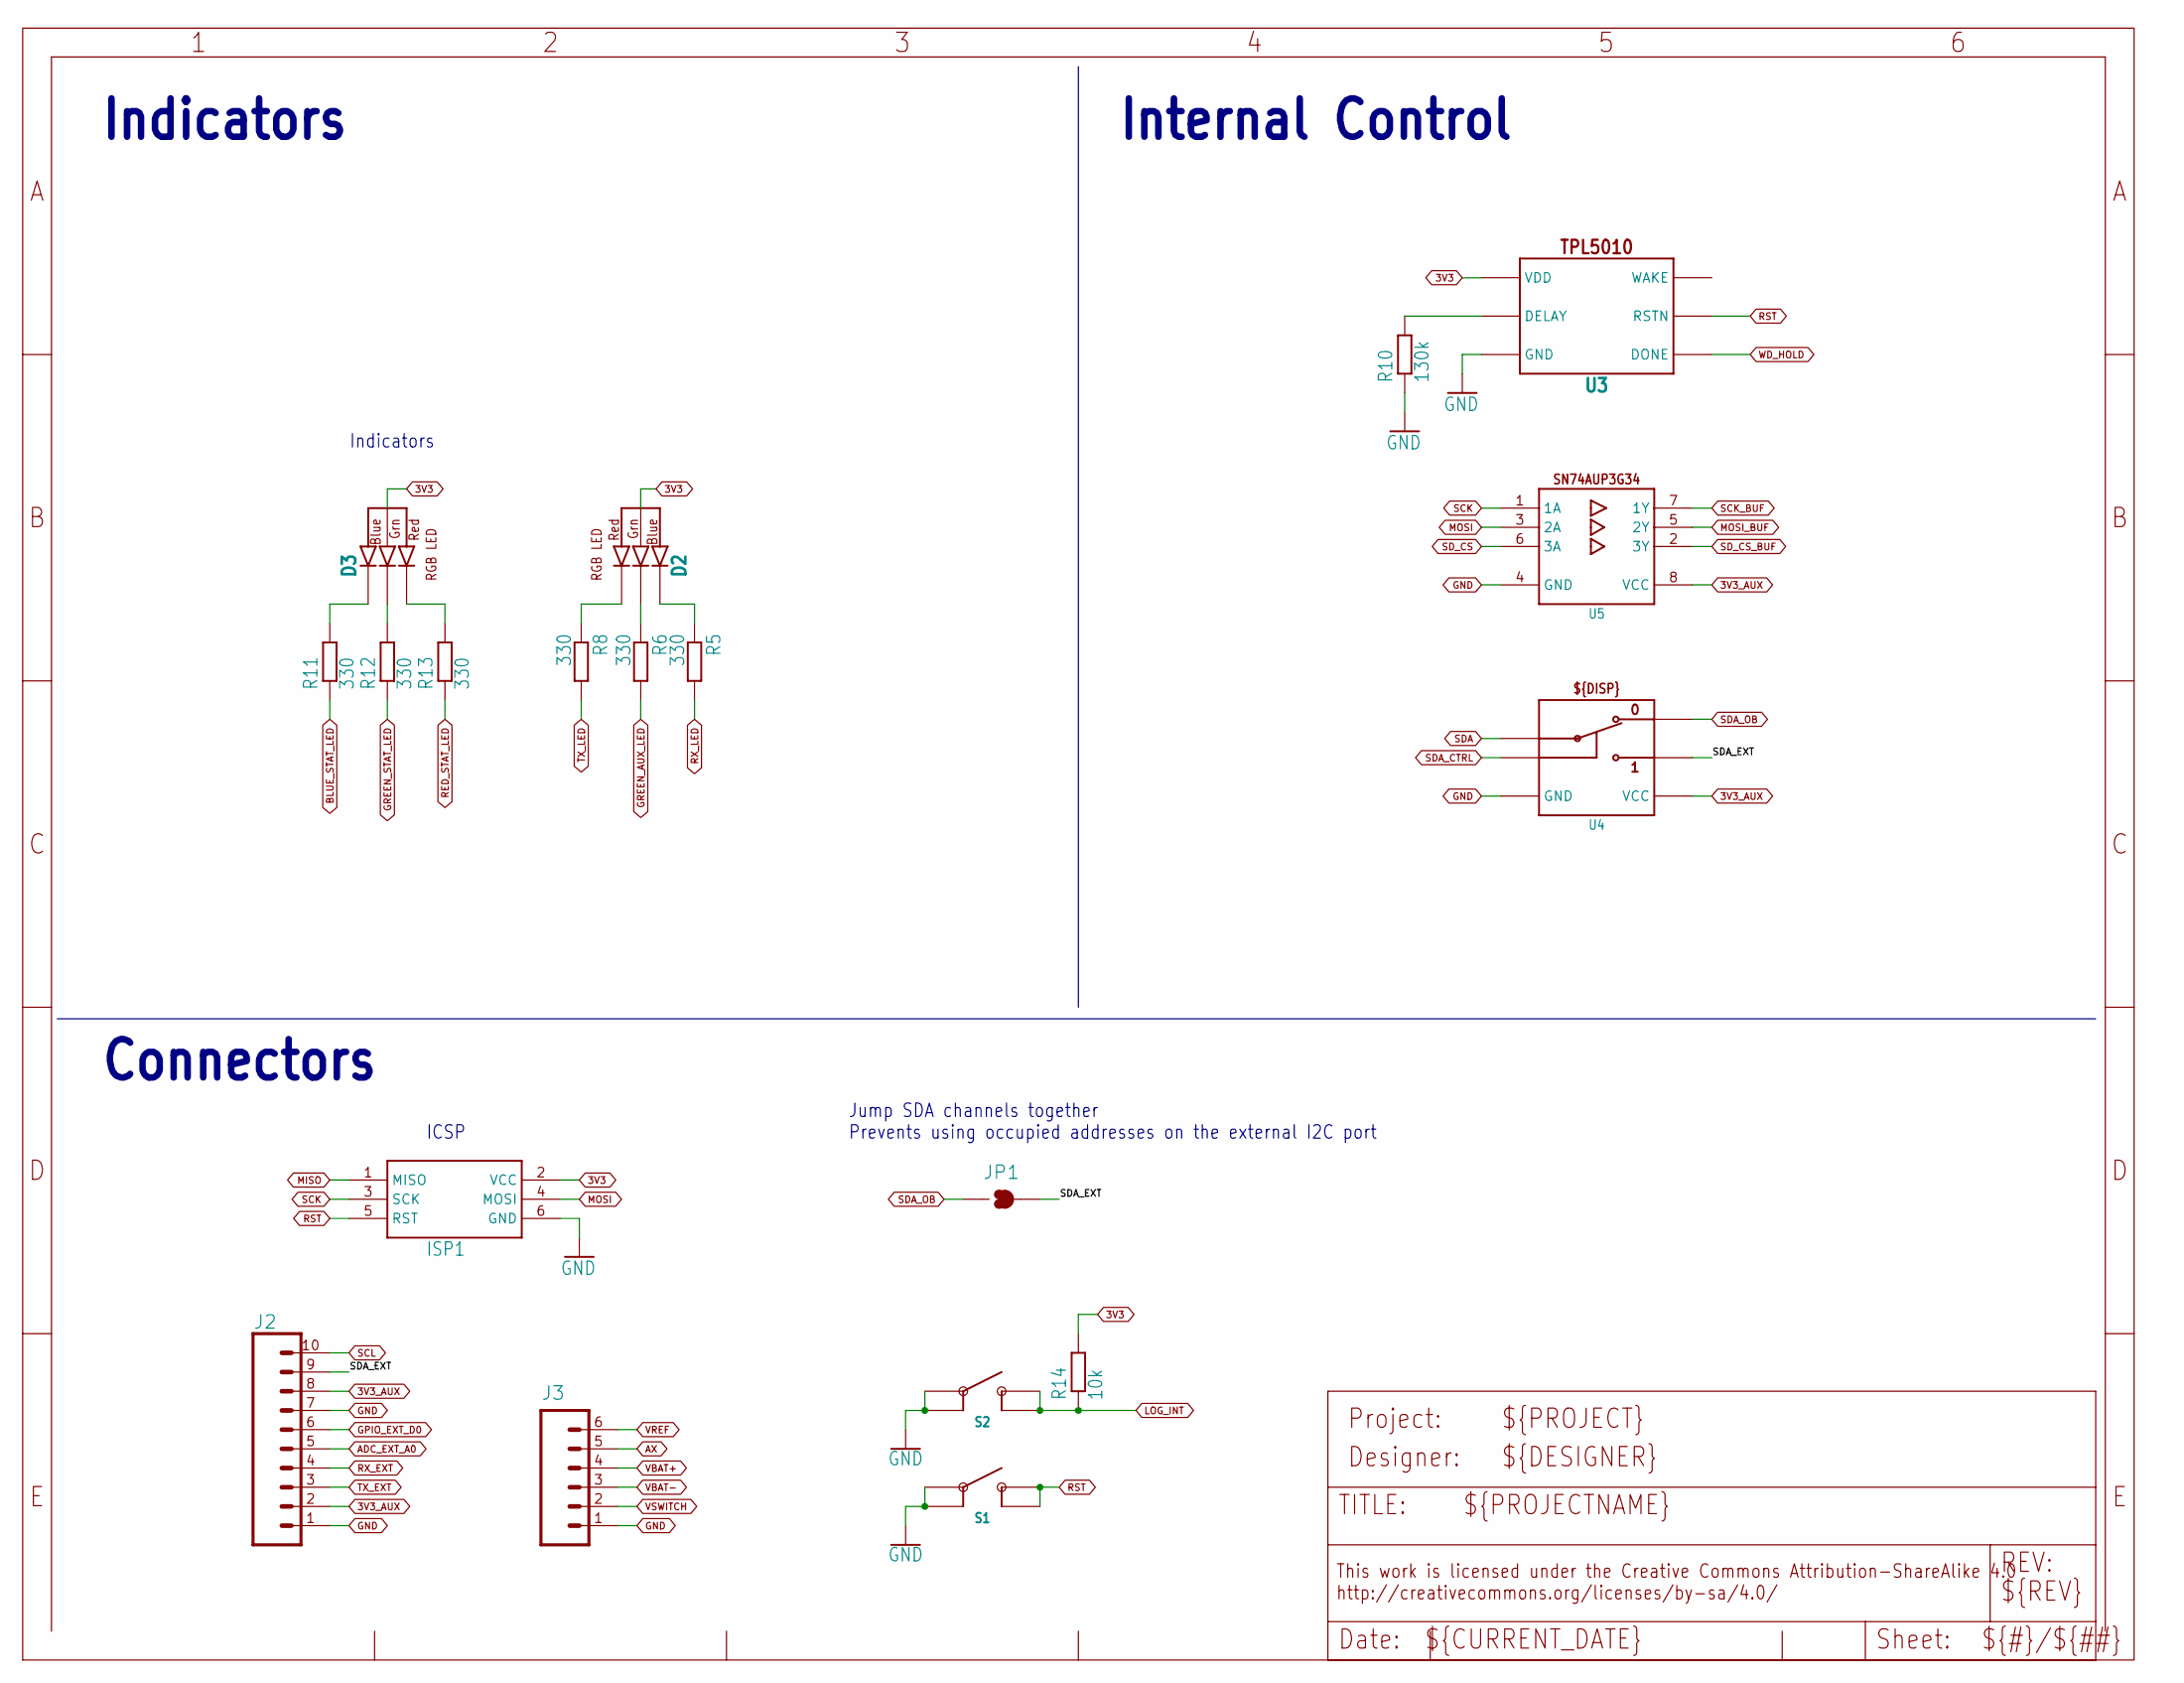
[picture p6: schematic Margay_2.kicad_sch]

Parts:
D2, D3: CLVBA-FKA; MPN CLVBA-FKA-CAEDH8BBB7A363; DIGIKEY CLVBA-FKA-CAEDH8BBB7A363CT-ND
ISP1: AVRISP-6; AVRISP; MPN 67997-206HLF; DIGIKEY 609-3234-ND
J2: CONN_102.54_SCREW; 1X10_SCREW; MPN OSTVN10A150; DIGIKEY ED10567-ND
J3: CONN_6SCREW_2.54; 1X06_SCREW; MPN OSTVN06A150; DIGIKEY ED10565-ND
JP1: JUMPER-SMT_2_NO_SILK; SMT-JUMPER_2_NO_SILK; MPN N/A; DIGIKEY DNP
R5, R6, R8, R11, R12, R13: 330; R0402; MPN RC0402FR-07330RL; DIGIKEY 311-330LRCT-ND
R10: 130k; R0603; MPN RC0603FR-07130KL; DIGIKEY 311-130KHRCT-ND
R14: 10k; R0402; MPN RC0402FR-0710KL; DIGIKEY 311-10.0KLRCT-ND
S1, S2: BUTTON4.2X3.2; SWITCH_4.2X3.2; MPN PTS810 SJG 250 SMTR LFS; DIGIKEY CKN10504CT-ND
U3: TPL5010DDC; DDC_R-PDSO-G6; MPN TPL5010DDCT; DIGIKEY 296-38829-1-ND
U4: SN74LVC1G3157SC70; DCK_R-PDSO-G6; MPN SN74LVC1G3157DCKR; DIGIKEY 296-14909-1-ND
U5: SN74AUP3G34DCU; DCU_(R-PDSO-G8); MPN SN74AUP3G34DCUR; DIGIKEY 296-25595-1-ND

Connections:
3V3: D2.2 (ANODE), D3.2 (ANODE), ISP1.2 (VCC), R14.2, U3.1 (VDD); also elsewhere on the board
3V3_AUX: J2.2, J2.8, U4.5 (VCC), U5.8 (VCC); also elsewhere on the board
/Margay_2/SDA_EXT: J2.9, JP1.2, U4.1 (B2)
ADC_EXT_A0: J2.5; also elsewhere on the board
AX: J3.5; also elsewhere on the board
BLUE_STAT_LED: R11.1; also elsewhere on the board
GND: ISP1.6 (GND), J2.1, J2.7, J3.1, R10.1, S1.1, S1.2, S2.1, S2.2, U3.2 (GND), U4.2 (GND), U5.4 (GND); also elsewhere on the board
GPIO_EXT_D0: J2.6; also elsewhere on the board
GREEN_AUX_LED: R6.2; also elsewhere on the board
GREEN_STAT_LED: R12.1; also elsewhere on the board
LOG_INT: R14.1, S2.3 (4), S2.4 (3); also elsewhere on the board
MISO: ISP1.1 (MISO); also elsewhere on the board
MOSI: ISP1.4 (MOSI), U5.3 (2A); also elsewhere on the board
MOSI_BUF: U5.5 (2Y); also elsewhere on the board
unnamed: D2.3 (BLUE_CATH), R5.1
unnamed: D2.4 (GREEN_CATH), R6.1
unnamed: D2.1 (RED_CATH), R8.1
unnamed: D3.3 (BLUE_CATH), R11.2
unnamed: D3.4 (GREEN_CATH), R12.2
unnamed: D3.1 (RED_CATH), R13.2
unnamed: R10.2, U3.3 (DELAY)
RED_STAT_LED: R13.1; also elsewhere on the board
RST: ISP1.5 (RST), S1.3 (4), S1.4 (3), U3.6 (RSTN); also elsewhere on the board
RX_EXT: J2.4; also elsewhere on the board
RX_LED: R5.2; also elsewhere on the board
SCK: ISP1.3 (SCK), U5.1 (1A); also elsewhere on the board
SCK_BUF: U5.7 (1Y); also elsewhere on the board
SCL: J2.10; also elsewhere on the board
SDA: U4.4 (A); also elsewhere on the board
SDA_CTRL: U4.6 (S); also elsewhere on the board
SDA_OB: JP1.1, U4.3 (B1); also elsewhere on the board
SD_CS: U5.6 (3A); also elsewhere on the board
SD_CS_BUF: U5.2 (3Y); also elsewhere on the board
TX_EXT: J2.3; also elsewhere on the board
TX_LED: R8.2; also elsewhere on the board
VBAT+: J3.4; also elsewhere on the board
VBAT-: J3.3; also elsewhere on the board
VREF: J3.6; also elsewhere on the board
VSWITCH: J3.2; also elsewhere on the board
WD_HOLD: U3.4 (DONE); also elsewhere on the board

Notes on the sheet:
Jump SDA channels together Prevents using occupied addresses on the external I2C port
ICSP
Indicators
Internal Control
Connectors

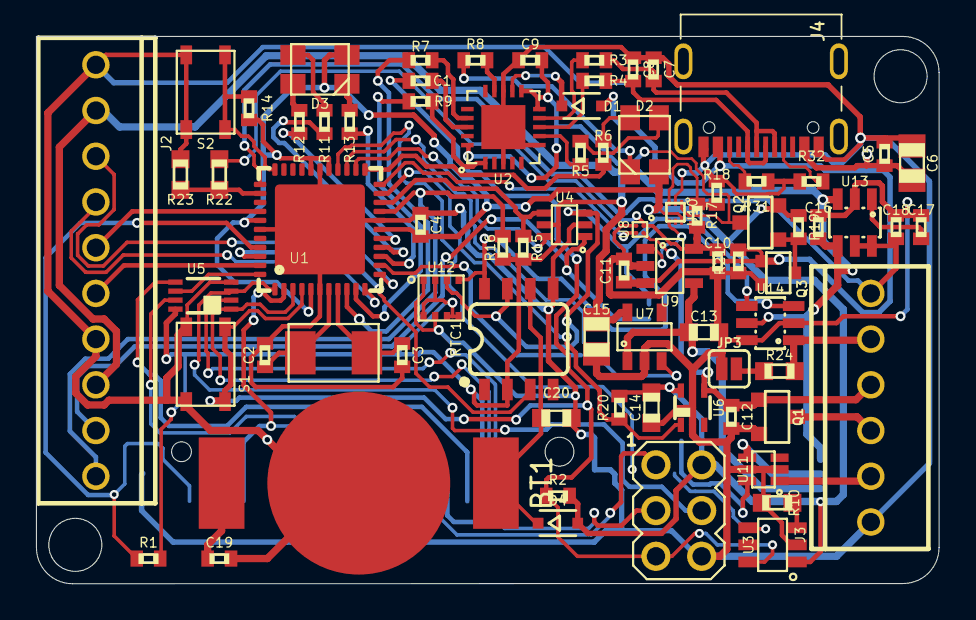
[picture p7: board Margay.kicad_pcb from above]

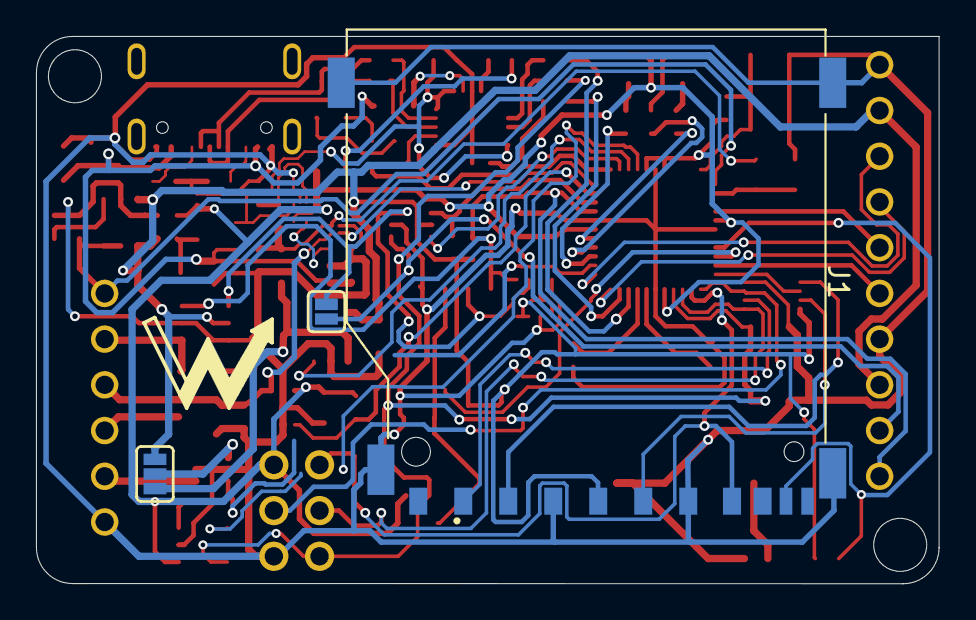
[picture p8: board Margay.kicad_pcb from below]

Board: 2 copper layers, 50.1 x 30.4 mm, 84 parts (4 on the bottom side), 72 nets.

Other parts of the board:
U$2: NWLOGO_MED

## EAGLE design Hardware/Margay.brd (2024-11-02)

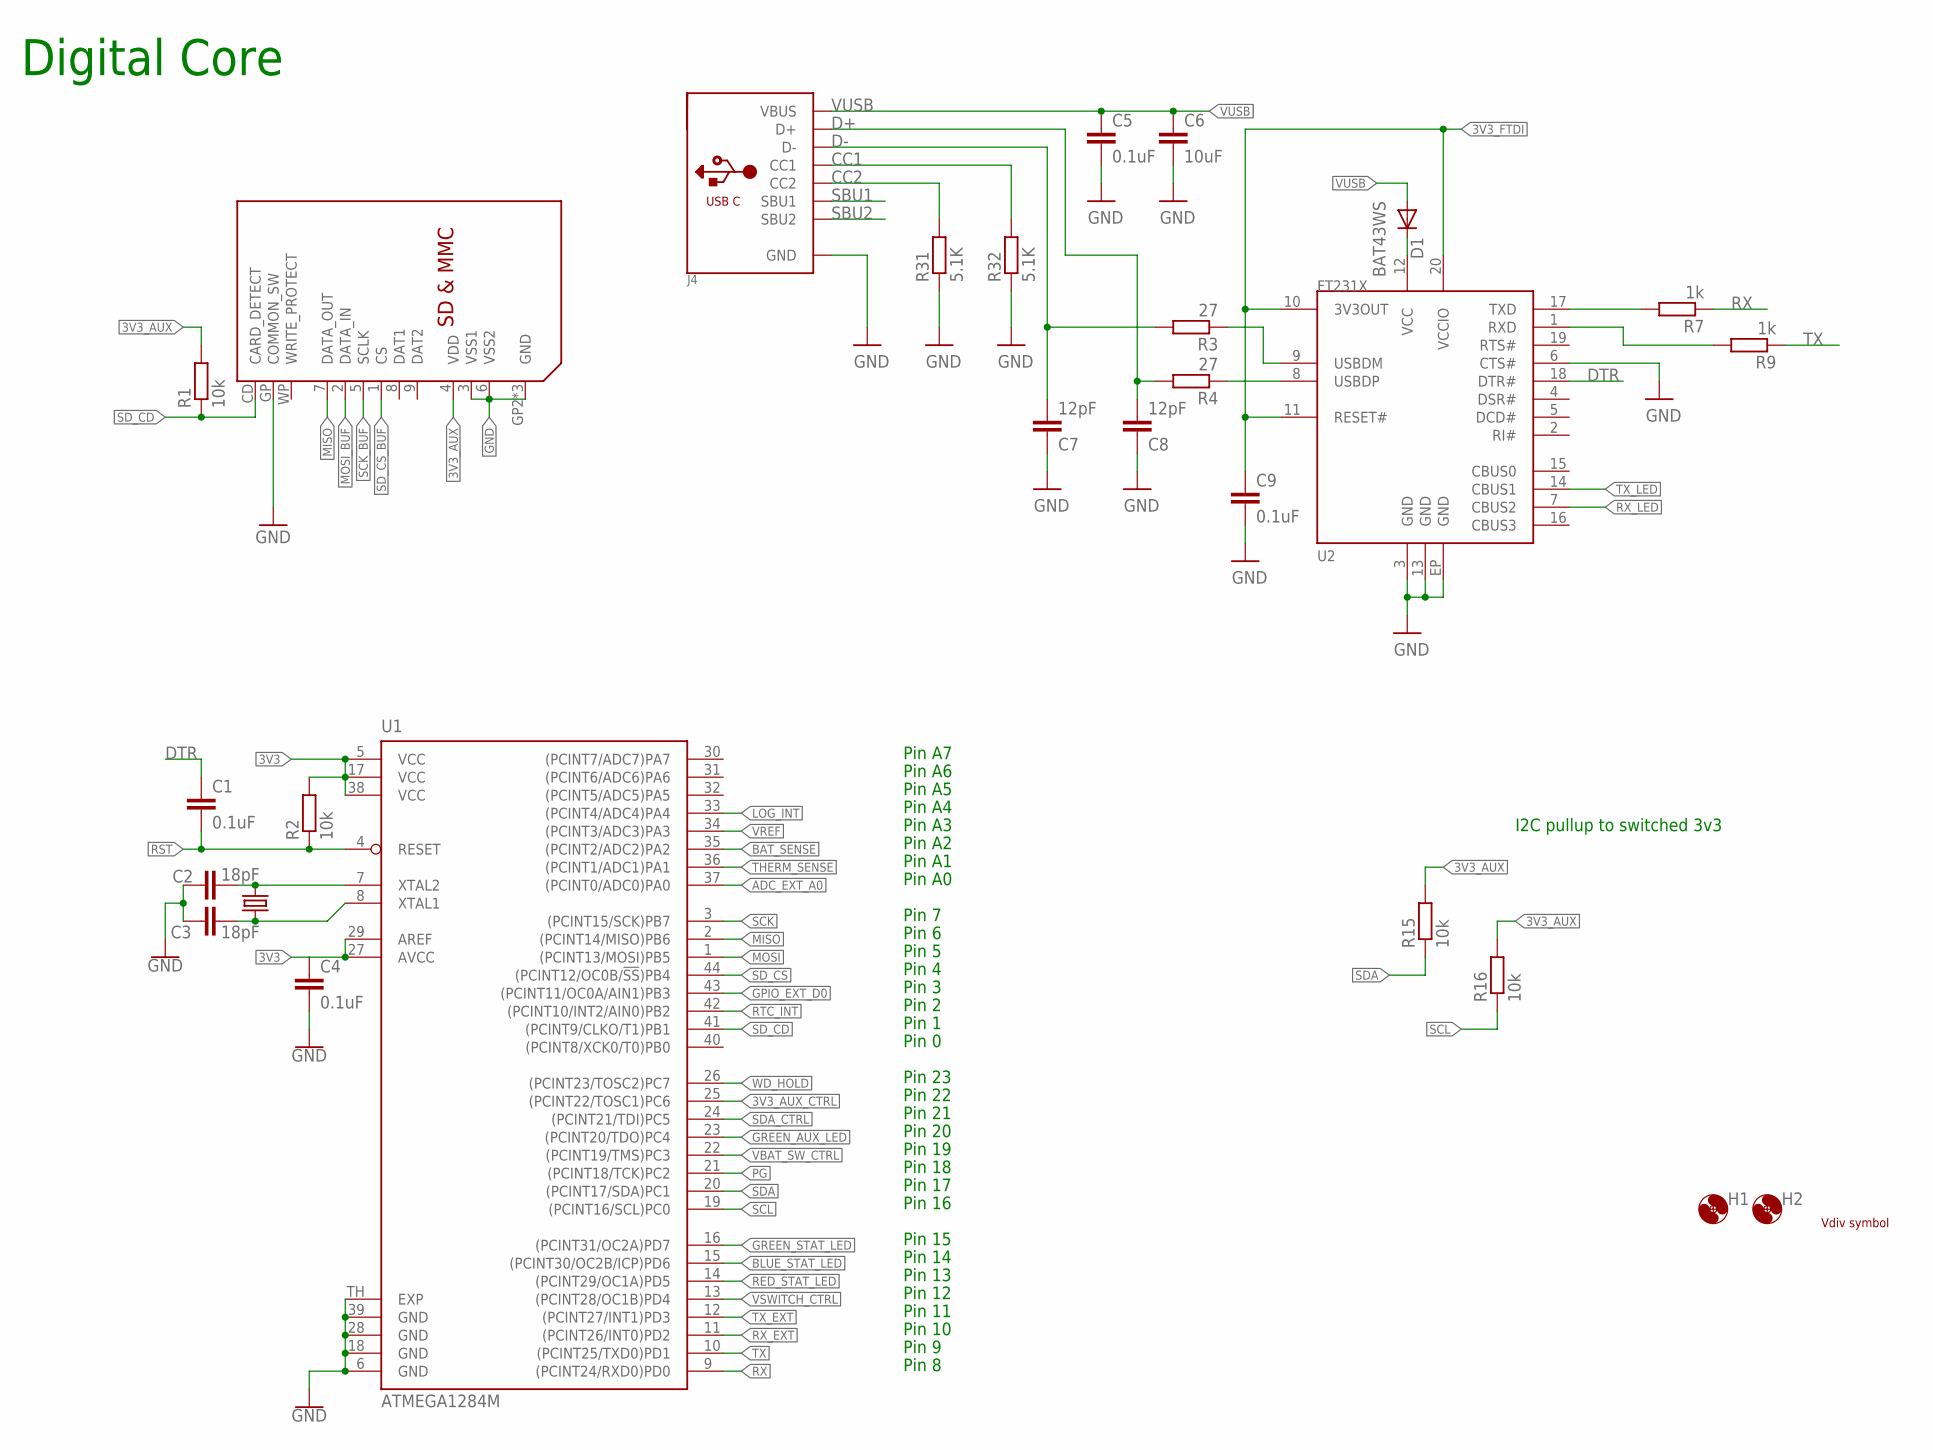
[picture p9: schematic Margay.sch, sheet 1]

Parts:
C1, C4, C5, C9: 0.1uF; C0402
C2, C3: 18pF; C0402
C6: 10uF; C0805
C7, C8: 12pF; C0402
D1: BAT43WS; SOD323-R; MPN BAT43WS-7-F; DIGIKEY BAT43WS-FDICT-ND
H1, H2: MOUNTING_HOLE4_NP_CLOSE; 4_40_CLOSE
J1: SDMMCWR-CRD; SD_WURTH_WR-CRD
J4: USB_C; USB_C_CUSB31-CFM2AX-01-X; MPN USB4105-GF-A; DIGIKEY 2073-USB4105-GF-ACT-ND
R1, R2, R15, R16: 10k; R0402
R3, R4: 27; R0402
R7, R9: 1k; R0402; MPN RC0603FR-07330RL
R31, R32: 5.1K; R0402
U1: ATMEGA1284M; MLF44-TH
U2: FT231X-Q; QFN20
U$1: VDIV_MARGAYFULL-VDIV; VDIV_MARGAY_2021; MPN N/A; DIGIKEY DNP
XTAL1: CRYSTAL8MHZ5X3.2; CRYSTAL_5X3.2_2-SMD; MPN ECS-80-18-30-JGN-TR; DIGIKEY XC2103CT-ND

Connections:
3V3: C4.1, R2.2, U1.5 (VCC), U1.17 (VCC), U1.27 (AVCC), U1.29 (AREF), U1.38 (VCC); also elsewhere on the board
3V3_AUX: J1.4 (VDD), R1.2, R15.2, R16.2; also elsewhere on the board
3V3_AUX_CTRL: U1.25 ((PCINT22/TOSC1)PC6); also elsewhere on the board
3V3_FTDI: C9.1, U2.10 (3V3OUT), U2.11 (RESET#), U2.20 (VCCIO); also elsewhere on the board
ADC_EXT_A0: U1.37 ((PCINT0/ADC0)PA0); also elsewhere on the board
BAT_SENSE: U1.35 ((PCINT2/ADC2)PA2); also elsewhere on the board
BLUE_STAT_LED: U1.15 ((PCINT30/OC2B/ICP)PD6); also elsewhere on the board
CC1: J4.A5 (CC1), R32.2
CC2: J4.B5 (CC2), R31.2
D+: C8.2, J4.A6 (D+), J4.B6 (D+), R4.2
D-: C7.2, J4.A7 (D-), J4.B7 (D-), R3.2
DTR: C1.1, U2.18 (DTR#)
GND: C2.1, C3.1, C4.2, C5.2, C6.2, C7.1, C8.1, C9.2, J1.3 (VSS1), J1.6 (VSS2), J1.GP (COMMON_SW), J1.GP2 (GND), J1.GP3 (GND), J1.GP4 (GND), J4.A1B12 (GND), J4.B1A12 (GND), R31.1, R32.1, U1.6 (GND), U1.18 (GND), U1.28 (GND), U1.39 (GND), U1.TH (EXP), U2.3 (GND), U2.6 (CTS#), U2.13 (GND), U2.EP (GND); also elsewhere on the board
GPIO_EXT_D0: U1.43 ((PCINT11/OC0A/AIN1)PB3); also elsewhere on the board
GREEN_AUX_LED: U1.23 ((PCINT20/TDO)PC4); also elsewhere on the board
GREEN_STAT_LED: U1.16 ((PCINT31/OC2A)PD7); also elsewhere on the board
LOG_INT: U1.33 ((PCINT4/ADC4)PA4); also elsewhere on the board
MISO: J1.7 (DATA_OUT), U1.2 ((PCINT14/MISO)PB6); also elsewhere on the board
MOSI: U1.1 ((PCINT13/MOSI)PB5); also elsewhere on the board
MOSI_BUF: J1.2 (DATA_IN); also elsewhere on the board
unnamed: D1.C, U2.12 (VCC)
unnamed: R7.2, U2.17 (TXD)
unnamed: R9.2, U2.1 (RXD)
unnamed: R4.1, U2.8 (USBDP)
unnamed: R3.1, U2.9 (USBDM)
PG: U1.21 ((PCINT18/TCK)PC2); also elsewhere on the board
RED_STAT_LED: U1.14 ((PCINT29/OC1A)PD5); also elsewhere on the board
RST: C1.2, R2.1, U1.4 (RESET); also elsewhere on the board
RTC_INT: U1.42 ((PCINT10/INT2/AIN0)PB2); also elsewhere on the board
RX: R7.1, U1.9 ((PCINT24/RXD0)PD0)
RX_EXT: U1.11 ((PCINT26/INT0)PD2); also elsewhere on the board
RX_LED: U2.7 (CBUS2); also elsewhere on the board
SBU1: J4.A8 (SBU1)
SBU2: J4.B8 (SBU2)
SCK: U1.3 ((PCINT15/SCK)PB7); also elsewhere on the board
SCK_BUF: J1.5 (SCLK); also elsewhere on the board
SCL: R16.1, U1.19 ((PCINT16/SCL)PC0); also elsewhere on the board
SDA: R15.1, U1.20 ((PCINT17/SDA)PC1); also elsewhere on the board
SDA_CTRL: U1.24 ((PCINT21/TDI)PC5); also elsewhere on the board
SD_CD: J1.CD (CARD_DETECT), R1.1, U1.41 ((PCINT9/CLKO/T1)PB1)
SD_CS: U1.44 ((PCINT12/OC0B/!SS!)PB4); also elsewhere on the board
SD_CS_BUF: J1.1 (CS); also elsewhere on the board
THERM_SENSE: U1.36 ((PCINT1/ADC1)PA1)
TX: R9.1, U1.10 ((PCINT25/TXD0)PD1)
TX_EXT: U1.12 ((PCINT27/INT1)PD3); also elsewhere on the board
TX_LED: U2.14 (CBUS1); also elsewhere on the board
VBAT_SW_CTRL: U1.22 ((PCINT19/TMS)PC3); also elsewhere on the board
VREF: U1.34 ((PCINT3/ADC3)PA3); also elsewhere on the board
VSWITCH_CTRL: U1.13 ((PCINT28/OC1B)PD4); also elsewhere on the board
VUSB: C5.1, C6.1, D1.A, J4.A4B9 (VBUS), J4.B4A9 (VBUS); also elsewhere on the board
WD_HOLD: U1.26 ((PCINT23/TOSC2)PC7); also elsewhere on the board
XTAL1: C3.2, U1.8 (XTAL1), XTAL1.OSC1 (1)
XTAL2: C2.2, U1.7 (XTAL2), XTAL1.OSC2 (2)

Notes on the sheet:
Pin 12
Pin A7
Pin A6
Pin A5
Pin A4
Pin 15
Pin 23
Pin A3
Pin 19
Pin 14
Pin 13
Pin 3
Pin 2
Pin 1
Pin 4
Pin A0
Pin A1
Pin A2
Pin 20
Digital Core
Pin 11
Pin 10
Pin 9
Pin 8
Pin 16
Pin 17
Pin 18
Pin 21
Pin 22
Pin 0
Pin 5
Pin 6
Pin 7
I2C pullup to switched 3v3

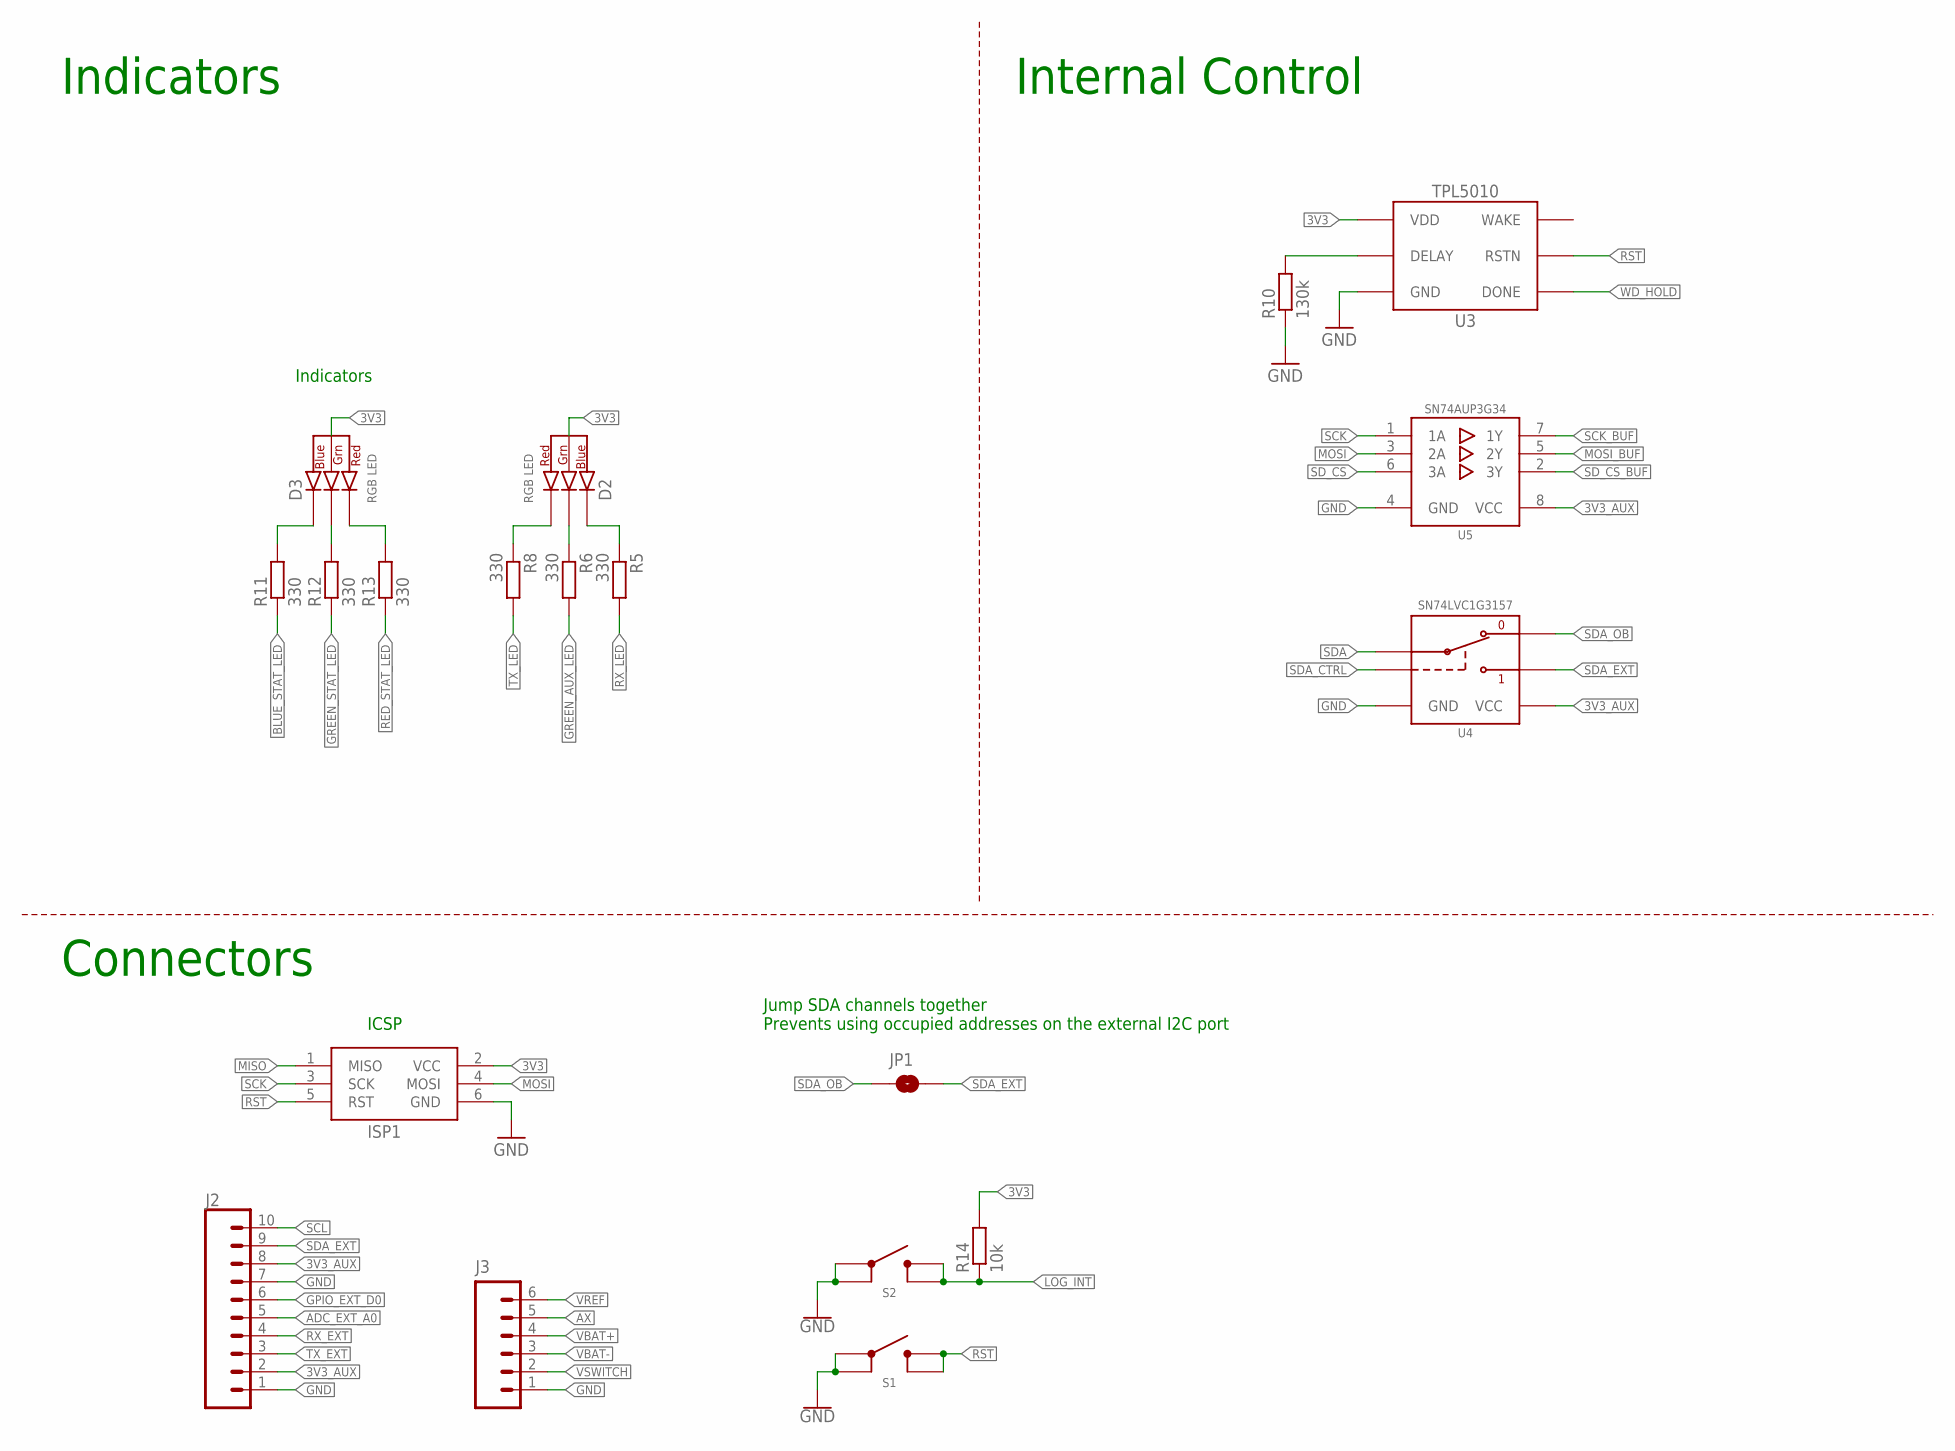
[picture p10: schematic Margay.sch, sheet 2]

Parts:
D2, D3: CLVBA-FKA
ISP1: AVRISP-6; AVRISP; MPN 67997-206HLF; DIGIKEY 609-3234-ND
J2: CONN_102.54_SCREW; 1X10_SCREW
J3: CONN_6SCREW_2.54; 1X06_SCREW
JP1: JUMPER-SMT_2_NO_SILK; SMT-JUMPER_2_NO_SILK
R5, R6, R8, R11, R12, R13: 330; R0402
R10: 130k; R0603
R14: 10k; R0402
S1, S2: BUTTON4.2X3.2; SWITCH_4.2X3.2
U3: TPL5010DDC; DDC_R-PDSO-G6
U4: SN74LVC1G3157SC70; DCK_R-PDSO-G6
U5: SN74AUP3G34DCU; DCU_(R-PDSO-G8)

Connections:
3V3: D2.2 (ANODE), D3.2 (ANODE), ISP1.2 (VCC), R14.2, U3.1 (VDD); also elsewhere on the board
3V3_AUX: J2.2, J2.8, U4.5 (VCC), U5.8 (VCC); also elsewhere on the board
ADC_EXT_A0: J2.5; also elsewhere on the board
AX: J3.5; also elsewhere on the board
BLUE_STAT_LED: R11.1; also elsewhere on the board
GND: ISP1.6 (GND), J2.1, J2.7, J3.1, R10.1, S1.1, S1.2, S2.1, S2.2, U3.2 (GND), U4.2 (GND), U5.4 (GND); also elsewhere on the board
GPIO_EXT_D0: J2.6; also elsewhere on the board
GREEN_AUX_LED: R6.2; also elsewhere on the board
GREEN_STAT_LED: R12.1; also elsewhere on the board
LOG_INT: R14.1, S2.3 (4), S2.4 (3); also elsewhere on the board
MISO: ISP1.1 (MISO); also elsewhere on the board
MOSI: ISP1.4 (MOSI), U5.3 (2A); also elsewhere on the board
MOSI_BUF: U5.5 (2Y); also elsewhere on the board
unnamed: R10.2, U3.3 (DELAY)
RED_STAT_LED: R13.1; also elsewhere on the board
RST: ISP1.5 (RST), S1.3 (4), S1.4 (3), U3.6 (RSTN); also elsewhere on the board
RX_EXT: J2.4; also elsewhere on the board
RX_LED: R5.2; also elsewhere on the board
SCK: ISP1.3 (SCK), U5.1 (1A); also elsewhere on the board
SCK_BUF: U5.7 (1Y); also elsewhere on the board
SCL: J2.10; also elsewhere on the board
SDA: U4.4 (A); also elsewhere on the board
SDA_CTRL: U4.6 (S); also elsewhere on the board
SDA_EXT: J2.9, JP1.2, U4.1 (B2)
SDA_OB: JP1.1, U4.3 (B1); also elsewhere on the board
SD_CS: U5.6 (3A); also elsewhere on the board
SD_CS_BUF: U5.2 (3Y); also elsewhere on the board
TX_EXT: J2.3; also elsewhere on the board
TX_LED: R8.2; also elsewhere on the board
VBAT+: J3.4; also elsewhere on the board
VBAT-: J3.3; also elsewhere on the board
VREF: J3.6; also elsewhere on the board
VSWITCH: J3.2; also elsewhere on the board
WD_HOLD: U3.4 (DONE); also elsewhere on the board
_BLUE_RX_AUX_LED: D2.3 (BLUE_CATH), R5.1
_BLUE_STAT_LED: D3.3 (BLUE_CATH), R11.2
_GREEN_AUX_LED: D2.4 (GREEN_CATH), R6.1
_GREEN_STAT_LED: D3.4 (GREEN_CATH), R12.2
_RED_STAT_LED: D3.1 (RED_CATH), R13.2
_RED_TX_AUX_LED: D2.1 (RED_CATH), R8.1

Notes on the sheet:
Jump SDA channels together Prevents using occupied addresses on the external I2C port
Indicators
ICSP
Connectors
Internal Control

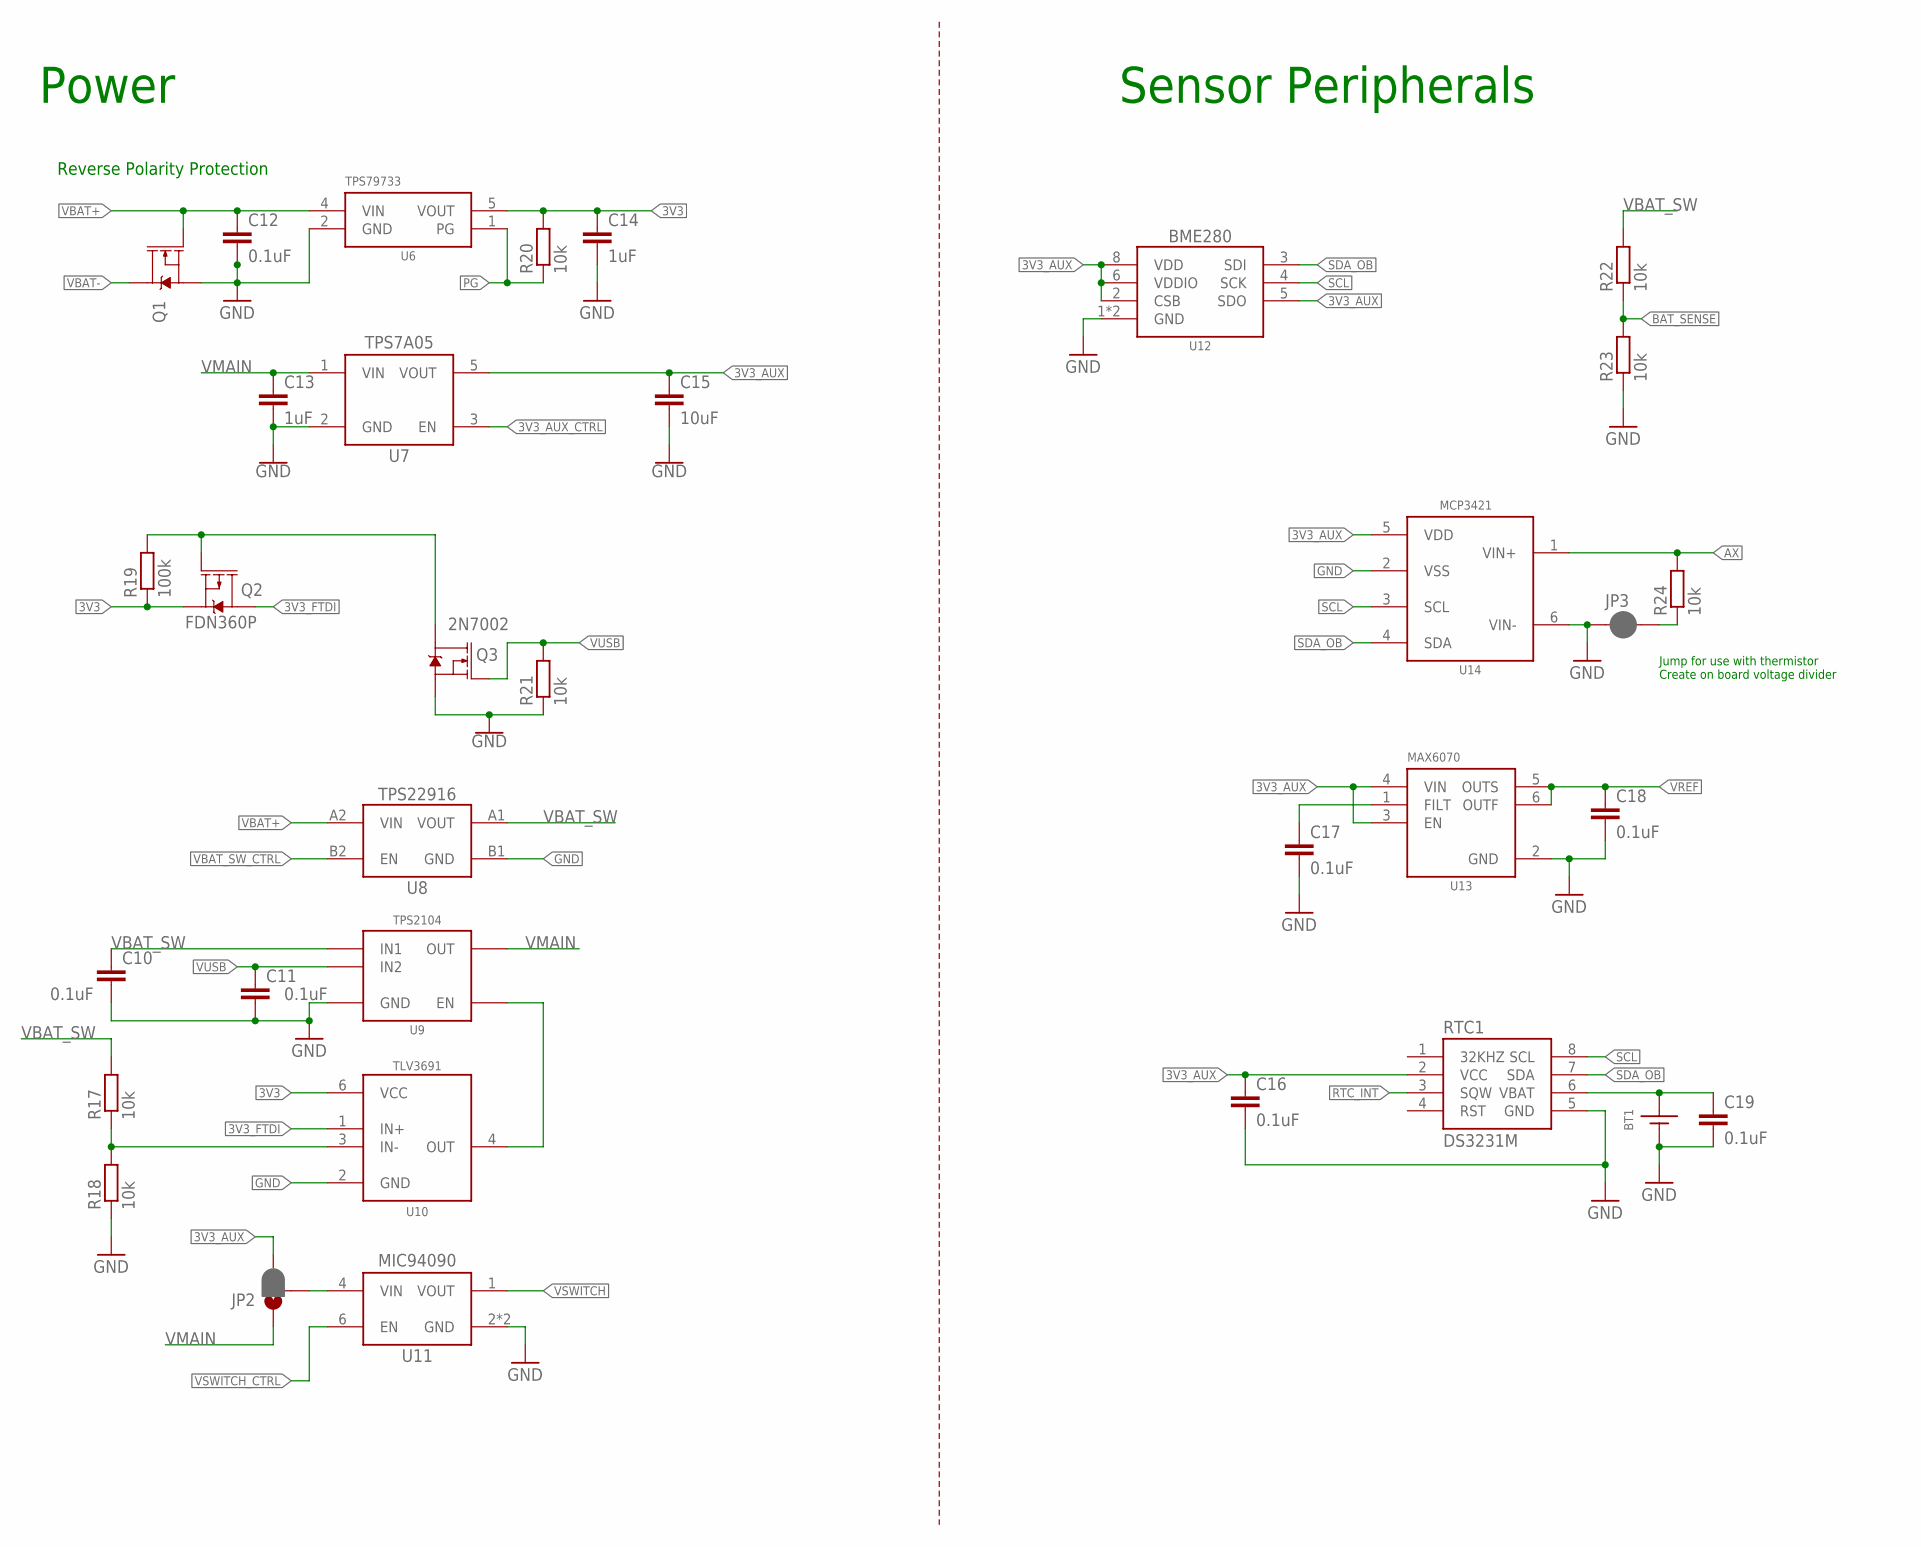
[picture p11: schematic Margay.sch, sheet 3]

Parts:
BT1: BATTERY_COIN12MM; LINX_BAT-HLD-012-SMT
C10, C11, C12, C16, C17, C18, C19: 0.1uF; C0402
C13, C14: 1uF; C0603
C15: 10uF; C0805
JP2: JUMPER-SMT_3_1-NC_PASTE_SILK; SMT-JUMPER_3_1-NC_PASTE_SILK
JP3: JUMPER-SMT_2_NC_PASTE_SILK; SMT-JUMPER_2_NC_PASTE_SILK
Q1: DMG3404; SOT23-3
Q2: FDN360P; SOT23-3@1; MPN DMP3099L-7; DIGIKEY DMP3099L-7DICT-ND
Q3: 2N7002; SOT323
R17, R18, R20, R21: 10k; R0402
R19: 100k; R0402
R22, R23: 10k; R0603
R24: 10k; R0603; MPN CRT0603-BY-1002ELF; DIGIKEY CRT0603-BY-1002ELFCT-ND
RTC1: DS3231M; SO08
U6: TPS79733; DCK_R-PDSO-G5
U7: TPS7A0533DBV; SOT23-5
U8: TPS22916YFP; YFP0004
U9: TPS2104; SOT23-5; MPN TPS2104DBVT; DIGIKEY 296-TPS2104DBVTCT-ND
U10: TLV3691DPF; DPF0006A
U11: MIC94090C6; SC-70_6
U12: BME280
U13: MAX6070AAUT18; SOT23-6L; MPN MAX6071AAUT18+T; DIGIKEY MAX6071AAUT18+TCT-ND
U14: MCP3421A1; SOT23-6L

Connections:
3V3: C14.1, Q2.2 (S), R19.1, R20.2, U6.5 (VOUT), U10.6 (VCC); also elsewhere on the board
3V3_AUX: C15.1, C16.1, JP2.3, RTC1.2 (VCC), U7.5 (VOUT), U12.2 (CSB), U12.5 (SDO), U12.6 (VDDIO), U12.8 (VDD), U13.3 (EN), U13.4 (VIN), U14.5 (VDD); also elsewhere on the board
3V3_AUX_CTRL: U7.3 (EN); also elsewhere on the board
3V3_FTDI: Q2.3 (D), U10.1 (IN+); also elsewhere on the board
AX: R24.2, U14.1 (VIN+); also elsewhere on the board
BAT_SENSE: R22.1, R23.2; also elsewhere on the board
GND: BT1.GND (-), C10.2, C11.2, C12.2, C13.2, C14.2, C15.2, C16.2, C17.2, C18.2, C19.2, JP3.1, Q1.2 (S), Q3.2 (S), R18.1, R21.1, R23.1, RTC1.5 (GND), U6.2 (GND), U7.2 (GND), U8.B1 (GND), U9.2 (GND), U10.2 (GND), U11.2 (GND), U11.5 (GND), U12.1 (GND), U12.7 (GND), U13.2 (GND), U14.2 (VSS), U14.6 (VIN-); also elsewhere on the board
unnamed: JP2.2, U11.4 (VIN)
unnamed: Q2.1 (G), Q3.3 (D), R19.2
unnamed: C17.1, U13.1 (FILT)
unnamed: R17.1, R18.2, U10.3 (IN-)
unnamed: U9.1 (EN), U10.4 (OUT)
PG: R20.1, U6.1 (PG); also elsewhere on the board
RTC_INT: RTC1.3 (SQW); also elsewhere on the board
SCL: RTC1.8 (SCL), U12.4 (SCK), U14.3 (SCL); also elsewhere on the board
SDA_OB: RTC1.7 (SDA), U12.3 (SDI), U14.4 (SDA); also elsewhere on the board
VBAT+: C12.1, Q1.1 (G), U6.4 (VIN), U8.A2 (VIN); also elsewhere on the board
VBAT-: Q1.3 (D); also elsewhere on the board
VBAT_SW: C10.1, R17.2, R22.2, U8.A1 (VOUT), U9.5 (IN1)
VBAT_SW_CTRL: U8.B2 (EN); also elsewhere on the board
VCOIN+: BT1.POWER0 (+), BT1.POWER1 (+), C19.1, RTC1.6 (VBAT)
VDIV_AX: JP3.2, R24.1
VMAIN: C13.1, JP2.1, U7.1 (VIN), U9.4 (OUT)
VREF: C18.1, U13.5 (OUTS), U13.6 (OUTF); also elsewhere on the board
VSWITCH: U11.1 (VOUT); also elsewhere on the board
VSWITCH_CTRL: U11.6 (EN); also elsewhere on the board
VUSB: C11.1, Q3.1 (G), R21.2, U9.3 (IN2); also elsewhere on the board

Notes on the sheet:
Reverse Polarity Protection
Power
Sensor Peripherals
Jump for use with thermistor Create on board voltage divider

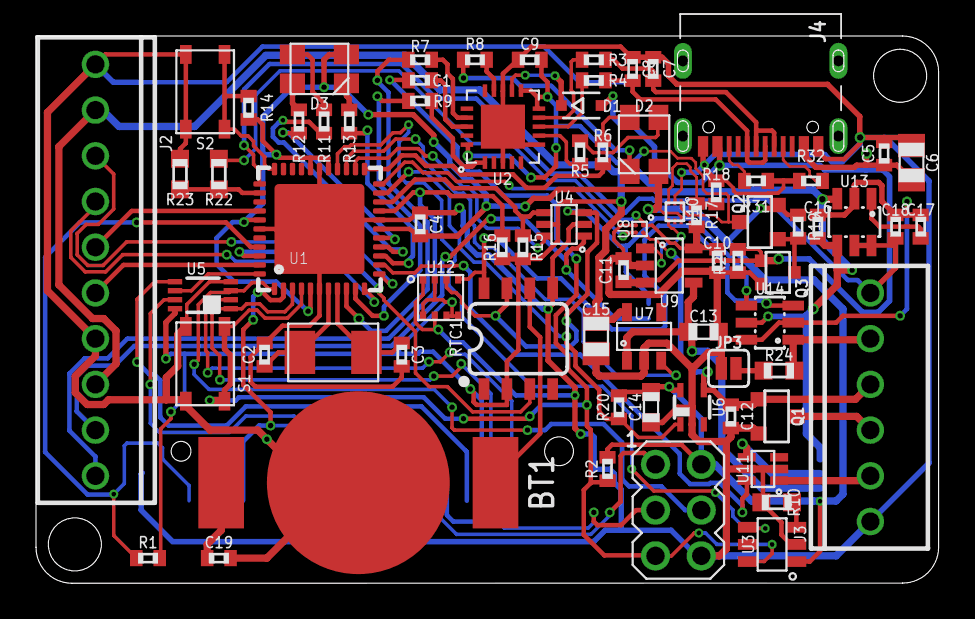
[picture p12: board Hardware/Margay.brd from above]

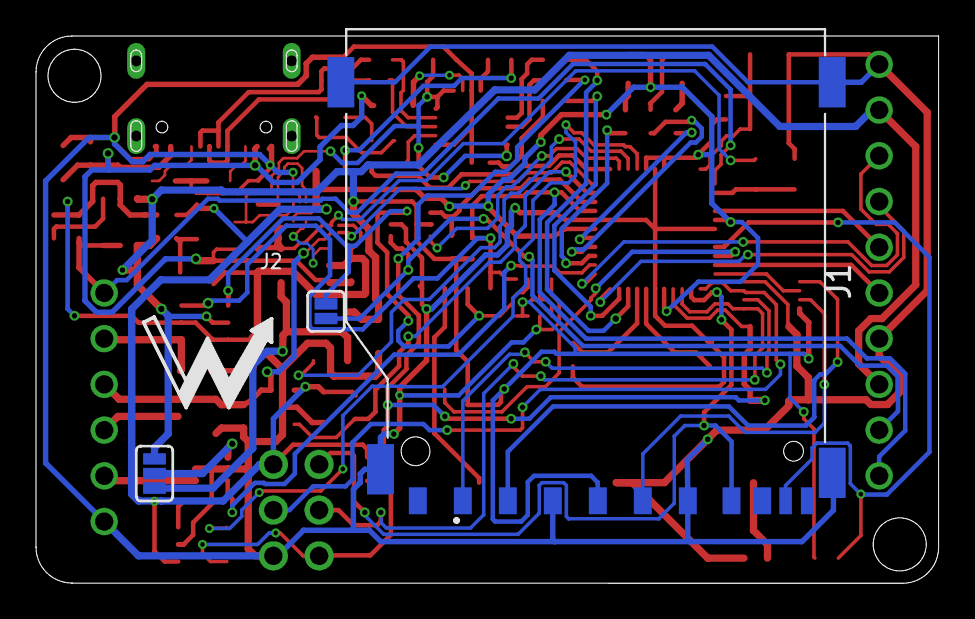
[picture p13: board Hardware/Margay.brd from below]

Board: 2 copper layers, 50.1 x 30.4 mm, 82 parts (4 on the bottom side), 72 nets.

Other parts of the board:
U$2: NWLOGO_MED

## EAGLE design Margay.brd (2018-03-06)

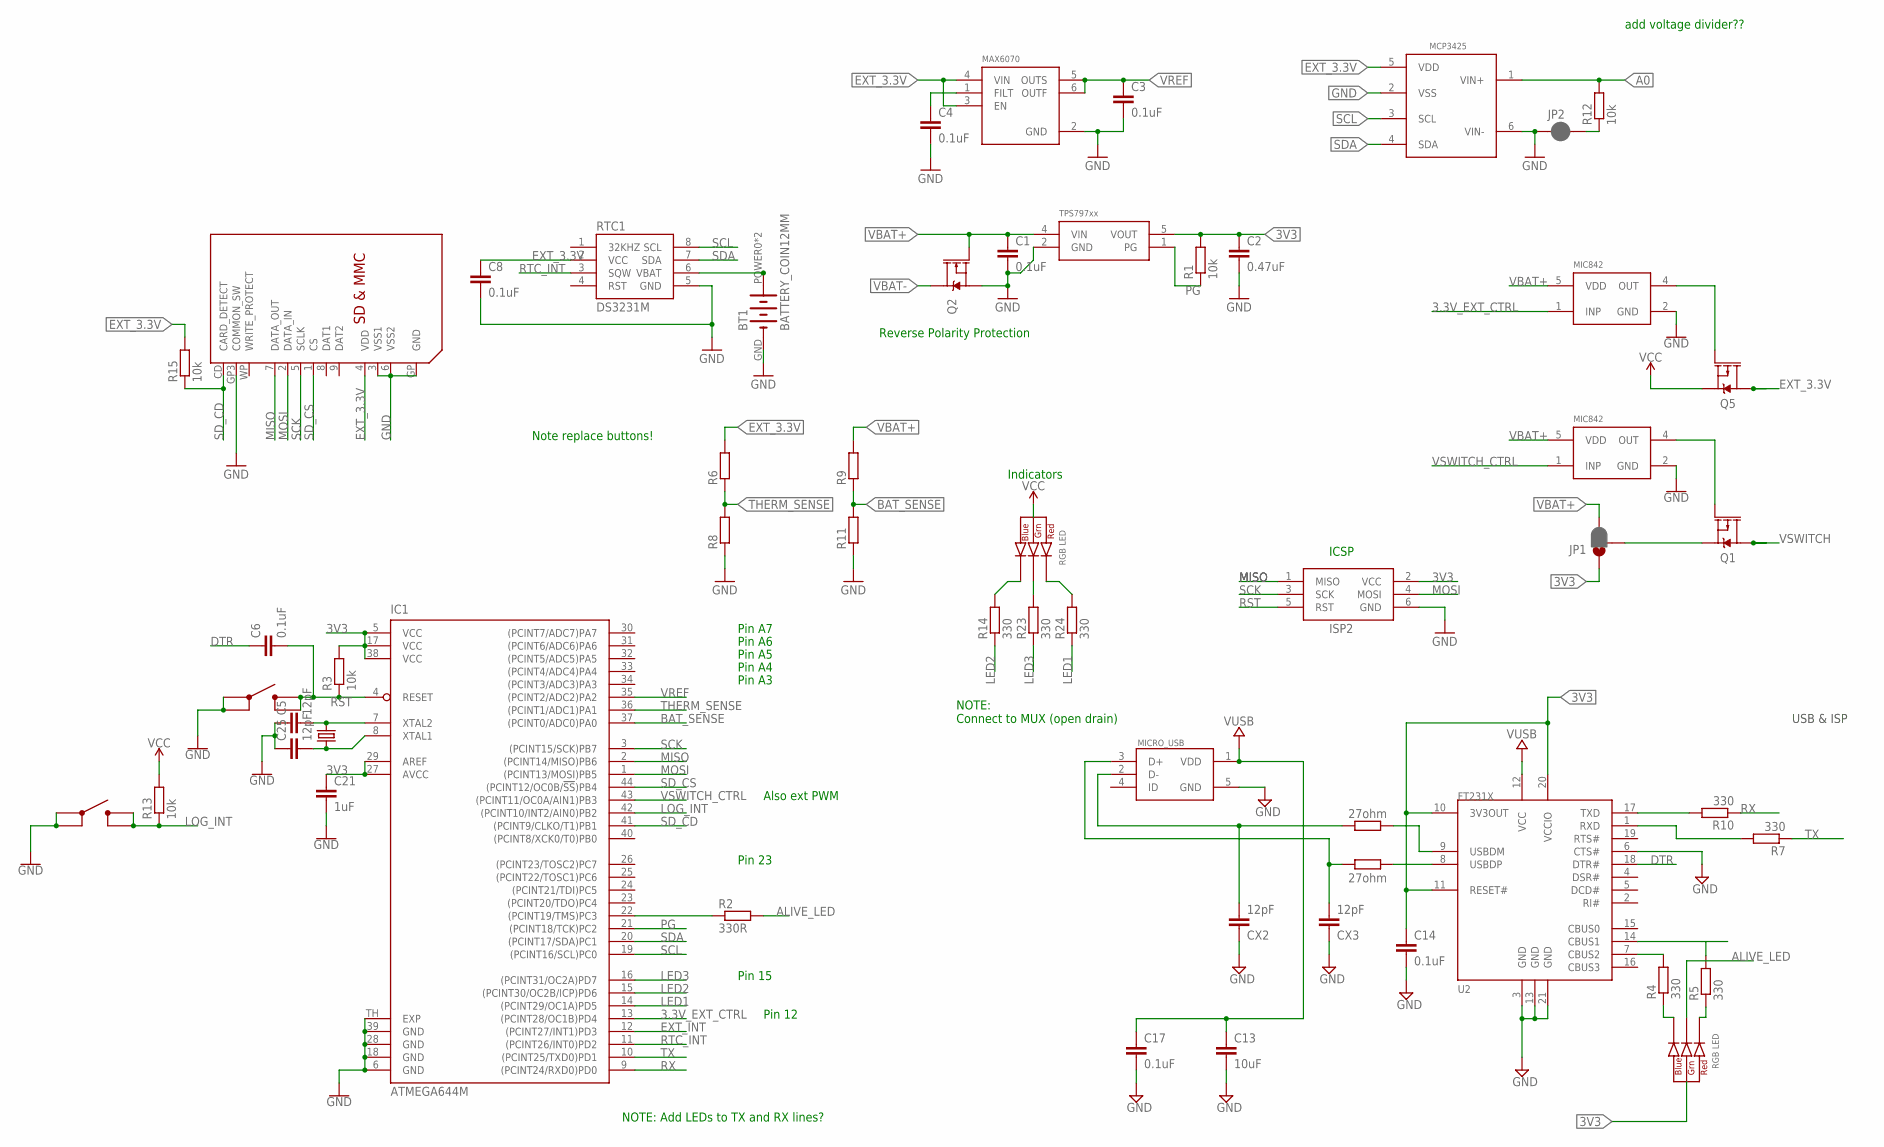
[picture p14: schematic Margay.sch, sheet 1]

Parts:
BT1: BATTERY_COIN12MM; AWICKERT_LINX_BAT-HLD-012-SMT
C1, C3, C4, C6, C8, C14, C17: 0.1uF; C0603
C2: 0.47uF; C0603
C5, C25: 12pF; C0603; MPN CL10C120JB8NNNC; DIGIKEY 1276-1254-1-ND
C13: 10uF; C0805
C21: 1uF; C0603; MPN CL10B105MO8NNWC; DIGIKEY 1276-6524-1-ND
CX2, CX3: 12pF; C0603
D+: 27ohm; R0603
D-: 27ohm; R0603
IC1: ATMEGA644M; MLF44-TH
ISP2: AVRISP-6; AVRISP; MPN 67997-206HLF; DIGIKEY 609-3234-ND
JP1: JUMPER-SMT_3_1-NC_PASTE_SILK; SMT-JUMPER_3_1-NC_PASTE_SILK
JP2: JUMPER-SMT_2_NC_PASTE_SILK; SMT-JUMPER_2_NC_PASTE_SILK
MICRO_USB: MICRO_USB_LONGPADS; 10118194-0001LF_10118194-0001LF_LONGER_PADS
Q1, Q5: MOSFET_PCH-IRLML2244; SOT23-3
Q2: MOSFET-NCH-DMG3404L; SOT23-3
R1, R12, R15: 10k; R0603
R2: 330R; R0603
R3, R13: 10k; R0603; DIGIKEY 311-10.0KHRCT-ND
R4, R7, R10, R14, R23, R24: 330; R0603; MPN RC0603FR-07330RL
R5: 330; R0603; MPN RC0603FR-07330RL; DIGIKEY 311-330HRCT-ND
R6, R8, R9, R11: R-EU_R0603; R0603
RTC1: DS3231M; SO08
U2: FT231X-Q; QFN20
U$1: CRYSTAL_5X3.2_2LEAD; CRYSTAL_5X3.2_2-SMD
U$3: SDMMC06132; 06132
U$4, U$18: MIC842; DCK_R-PDSO-G5
U$5, U$9: BUTTON4.2X3.2; SWITCH_4.2X3.2
U$6: TPS79733; DCK_R-PDSO-G5
U$7: MAX6070AAUT18; SOT23-6L
U$8: MCP3425; SOT23-6L
U$15, U$16: CLVBA-FKA

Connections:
3.3V_EXT_CTRL: IC1.13 ((PCINT28/OC1B)PD4), U$18.1 (INP)
3V3: C2.1, C14.1, C21.1, IC1.5 (VCC), IC1.17 (VCC), IC1.27 (AVCC), IC1.29 (AREF), IC1.38 (VCC), ISP2.2 (VCC), JP1.1, Q5.2 (S), R1.2, R3.2, R13.2, U2.10 (3V3OUT), U2.11 (RESET#), U2.20 (VCCIO), U$6.5 (VOUT), U$15.2 (ANODE), U$16.2 (ANODE)
A0: R12.2, U$8.1 (VIN+); also elsewhere on the board
ALIVE_LED: R2.2, U$16.4 (GREEN_CATH)
BAT_SENSE: IC1.37 ((PCINT0/ADC0)PA0), R9.1, R11.2
DTR: C6.1, U2.18 (DTR#)
EXT_3.3V: C8.1, Q5.3 (D), R6.2, R15.2, RTC1.2 (VCC), U$3.4 (VDD), U$7.3 (EN), U$7.4 (VIN), U$8.5 (VDD); also elsewhere on the board
EXT_INT: IC1.12 ((PCINT27/INT1)PD3); also elsewhere on the board
GND: BT1.GND (-), C1.2, C2.2, C3.2, C4.2, C5.1, C8.2, C13.2, C14.2, C17.2, C21.2, C25.1, CX2.1, CX3.1, IC1.6 (GND), IC1.18 (GND), IC1.28 (GND), IC1.39 (GND), IC1.TH (EXP), ISP2.6 (GND), JP2.1, MICRO_USB.5 (GND), Q2.2 (S), R8.1, R11.1, RTC1.5 (GND), U2.3 (GND), U2.6 (CTS#), U2.13 (GND), U2.21 (GND), U$3.3 (VSS1), U$3.6 (VSS2), U$3.GP (GND), U$3.GP3 (COMMON_SW), U$4.2 (GND), U$5.1, U$5.2, U$6.2 (GND), U$7.2 (GND), U$8.2 (VSS), U$8.6 (VIN-), U$9.1, U$9.2, U$18.2 (GND); also elsewhere on the board
LED1: IC1.14 ((PCINT29/OC1A)PD5), R24.1
LED2: IC1.15 ((PCINT30/OC2B/ICP)PD6), R14.1
LED3: IC1.16 ((PCINT31/OC2A)PD7), R23.1
LOG_INT: IC1.42 ((PCINT10/INT2/AIN0)PB2), R13.1, U$5.3 (4), U$5.4 (3)
MISO: IC1.2 ((PCINT14/MISO)PB6), ISP2.1 (MISO), U$3.7 (DATA_OUT); also elsewhere on the board
MOSI: IC1.1 ((PCINT13/MOSI)PB5), ISP2.4 (MOSI), U$3.2 (DATA_IN); also elsewhere on the board
unnamed: IC1.22 ((PCINT19/TMS)PC3), R2.1
unnamed: Q1.1 (G), U$4.4 (OUT)
unnamed: JP1.2, Q1.2 (S)
unnamed: C5.2, IC1.7 (XTAL2), U$1.OSC2 (2)
unnamed: Q5.1 (G), U$18.4 (OUT)
unnamed: C25.2, IC1.8 (XTAL1), U$1.OSC1 (1)
unnamed: R14.2, U$15.3 (BLUE_CATH)
unnamed: R23.2, U$15.4 (GREEN_CATH)
unnamed: C4.1, U$7.1 (FILT)
unnamed: JP2.2, R12.1
unnamed: R24.2, U$15.1 (RED_CATH)
unnamed: R5.1, U$16.1 (RED_CATH)
unnamed: R10.2, U2.17 (TXD)
unnamed: R4.1, U$16.3 (BLUE_CATH)
unnamed: BT1.POWER0 (+), BT1.POWER1 (+), RTC1.6 (VBAT)
unnamed: R7.2, U2.1 (RXD)
unnamed: CX3.2, D+.2, MICRO_USB.3 (D+)
unnamed: CX2.2, D-.2, MICRO_USB.2 (D-)
unnamed: D+.1, U2.8 (USBDP)
unnamed: R4.2, U2.7 (CBUS2)
unnamed: R5.2, U2.14 (CBUS1)
unnamed: D-.1, U2.9 (USBDM)
PG: IC1.21 ((PCINT18/TCK)PC2), R1.1, U$6.1 (PG)
RST: C6.2, IC1.4 (RESET), ISP2.5 (RST), R3.1, U$9.3 (4), U$9.4 (3)
RTC_INT: IC1.11 ((PCINT26/INT0)PD2), RTC1.3 (SQW)
RX: IC1.9 ((PCINT24/RXD0)PD0), R10.1
SCK: IC1.3 ((PCINT15/SCK)PB7), ISP2.3 (SCK), U$3.5 (SCLK); also elsewhere on the board
SCL: IC1.19 ((PCINT16/SCL)PC0), RTC1.8 (SCL), U$8.3 (SCL); also elsewhere on the board
SDA: IC1.20 ((PCINT17/SDA)PC1), RTC1.7 (SDA), U$8.4 (SDA); also elsewhere on the board
SD_CD: IC1.41 ((PCINT9/CLKO/T1)PB1), R15.1, U$3.CD (CARD_DETECT)
SD_CS: IC1.44 ((PCINT12/OC0B/!SS!)PB4), U$3.1 (CS)
THERM_SENSE: IC1.36 ((PCINT1/ADC1)PA1), R6.1, R8.2
TX: IC1.10 ((PCINT25/TXD0)PD1), R7.1
VBAT+: C1.1, JP1.3, Q2.1 (G), R9.2, U$4.5 (VDD), U$6.4 (VIN), U$18.5 (VDD); also elsewhere on the board
VBAT-: Q2.3 (D); also elsewhere on the board
VREF: C3.1, IC1.35 ((PCINT2/ADC2)PA2), U$7.5 (OUTS), U$7.6 (OUTF); also elsewhere on the board
VSWITCH: Q1.3 (D); also elsewhere on the board
VSWITCH_CTRL: IC1.43 ((PCINT11/OC0A/AIN1)PB3), U$4.1 (INP)
VUSB: C13.1, C17.1, MICRO_USB.1 (VDD), U2.12 (VCC)

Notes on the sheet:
Indicators
NOTE: Connect to MUX (open drain)
Note replace buttons!
Pin 12
Pin A7
Pin A6
Pin A5
Pin A4
Pin 15
NOTE: Add LEDs to TX and RX lines?
USB & ISP
Pin 23
Pin A3
Also ext PWM
ICSP
add voltage divider??
Reverse Polarity Protection

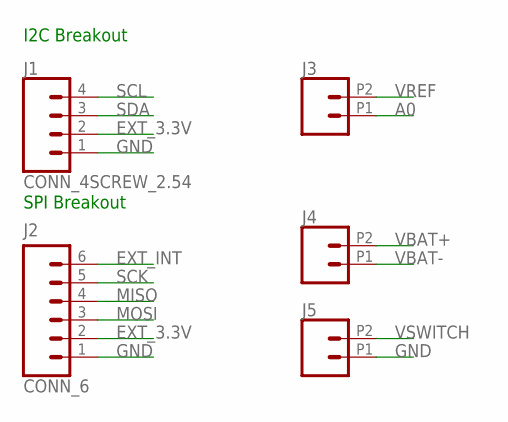
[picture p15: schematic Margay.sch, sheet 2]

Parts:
J1: CONN_4SCREW_2.54; 1X04
J2: CONN_6; 1X06_SCREW
J3, J4, J5: CONN_022.54MM_SCREWTERM; 1X02_2.54_SCREWTERM

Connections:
A0: J3.P1 (1); also elsewhere on the board
EXT_3.3V: J1.2, J2.2; also elsewhere on the board
EXT_INT: J2.6; also elsewhere on the board
GND: J1.1, J2.1, J5.P1 (1); also elsewhere on the board
MISO: J2.4; also elsewhere on the board
MOSI: J2.3; also elsewhere on the board
SCK: J2.5; also elsewhere on the board
SCL: J1.4; also elsewhere on the board
SDA: J1.3; also elsewhere on the board
VBAT+: J4.P2 (2); also elsewhere on the board
VBAT-: J4.P1 (1); also elsewhere on the board
VREF: J3.P2 (2); also elsewhere on the board
VSWITCH: J5.P2 (2); also elsewhere on the board

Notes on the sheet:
I2C Breakout
SPI Breakout



Board: 2 copper layers, 50.2 x 30.4 mm, 61 parts (3 on the bottom side), 54 nets.

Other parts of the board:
U$2: NWLOGO_MED

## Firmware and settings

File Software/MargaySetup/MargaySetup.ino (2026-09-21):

#include <SPI.h>
#include <Wire.h>
#include <DS3231.h>
#include <MCP3421.h>
#include <SD.h>
#include <avr/pgmspace.h>
#include <EEPROM.h>

MCP3421 adc;

boolean Debug = true;
char ReadArray[25] = {0};

const uint8_t VRef_Pin = 3;
const uint8_t ThermSense_Pin = 1;
const uint8_t BatSense_Pin = 2;

const uint8_t VSwitch_Pin = 12;
const uint8_t SD_CD = 1;

const uint8_t Ext3v3Ctrl = 19;
const uint8_t ExtInt = 11;

const uint8_t BatSwitch = 22;

const uint8_t BuiltInLED = 20;

const uint8_t RED = 13;
const uint8_t GREEN = 15;
const uint8_t BLUE = 14;

const uint8_t RGB[] = {RED, GREEN, BLUE};

const int SD_CS = 4;
char FileNameC[11];
boolean SD_Init = false;

DS3231 Clock;

void setup() {
  pinMode(Ext3v3Ctrl, OUTPUT);
  pinMode(BatSwitch, OUTPUT);
  digitalWrite(BatSwitch, HIGH);
  digitalWrite(Ext3v3Ctrl, HIGH);
  pinMode(9, OUTPUT);
  digitalWrite(9, LOW);
  pinMode(8, OUTPUT);
  digitalWrite(8, LOW);

  pinMode(BuiltInLED, OUTPUT);
  digitalWrite(BuiltInLED, HIGH);

  Serial.begin(38400);
  Serial.print("Loading...");

  Wire.begin();
  adc.setResolution(18);

  Serial.println("Done.");
  Serial.println("Enter When Ready...");
}

void loop() {
  static int ReadLength = 0;
  String ReadString;

  if(Serial.available() > 0) {
    char Input = Serial.read();

    if(Input != 13 || Input != 10) {
      ReadArray[ReadLength] = Input;
      ReadLength++;
    }

    if(Input == 13 || Input == 10) {
      ReadString = String(ReadArray);
      ReadString.trim();
      memset(ReadArray, 0, sizeof(ReadArray));
      ReadLength = 0;

      if(ReadString == "SD") {
        Serial.println("\nTesting SD");
        Serial.println(bool2pf(TestSD()));
      }

      if(ReadString == "Clock") {
        Serial.println("\nTesting Clock");
        Serial.println(bool2pf(TestClock()));
      }

      if(ReadString == "I2C") {
        Serial.println("\nI2C Test");
        I2CTest();
        Serial.println("End");
      }

      if(ReadString == "ADC Disp") {
        Serial.println("\nBegin ADC Test");
        ADCDisp();
        Serial.println("...End ADC Test");
      }

      if(ReadString == "IO") {
        Serial.println("\nIO Test");
        IOTest();
        Serial.println("End");
      }

      if(ReadString == "PG") {
        Serial.println("\nBegin PG Test");
        Serial.print("PG: ");
        Serial.println(bool2pf(PGTest()));
      }

      if(ReadString == "Power") {
        Serial.println("\nPower Test");
        PowerTest();
        Serial.println("End");
      }

      if(ReadString == "Button") {
        Serial.println("\nBegin Button Test");
        ButtonTest();
      }

      if(ReadString == "LED") {
        Serial.println("\nLED Test");
        LEDTest();
        Serial.println("End");
      }

      if(ReadString == "SN Set") {
        char Data[5] = {0};
        while(Serial.available() > 0) {
          int x = Serial.read();
        }
        Serial.print("Enter Board Type... ");
        while(Serial.available() == 0);
        String DeviceIDStr = Serial.readString();
        DeviceIDStr.toCharArray(Data, 5);
        uint16_t DeviceID = (int)strtol(Data, NULL, 16);
        Serial.println(DeviceID, HEX);

        Serial.print("Enter Group ID... ");
        while(Serial.available() == 0);
        String GroupIDStr = Serial.readString();
        GroupIDStr.toCharArray(Data, 5);
        uint16_t GroupID = (int)strtol(Data, NULL, 16);
        Serial.println(GroupID, HEX);

        Serial.print("Enter Unique ID... ");
        while(Serial.available() == 0);
        String UniIDStr = Serial.readString();
        UniIDStr.toCharArray(Data, 5);
        uint16_t UniID = (int)strtol(Data, NULL, 16);
        Serial.println(UniID, HEX);

        int Location = EEPROM.length() - 8;

        boolean Fault = false;
        uint16_t FirmwareID = 0x0000;
        uint16_t SerialNumber[] = {DeviceID, GroupID, UniID, FirmwareID};

        for(int i = 0; i < 4; i++) {
          EEPROM.write(Location, (SerialNumber[i] & 0xFF00) >> 8);
          EEPROM.write(Location + 1, SerialNumber[i] & 0xFF);
          Location += 2;
        }
        Location = EEPROM.length() - 8;

        for(int i = 0; i < 4; i++) {
          if(EEPROM.read(Location) != (SerialNumber[i] & 0xFF00) >> 8 ||
             EEPROM.read(Location + 1) != (SerialNumber[i] & 0xFF)) {
            Fault = true;
          }
          Location += 2;
        }

        if(Fault == true) {
          Serial.println("CRITICAL ERROR: Readback Failed, try again");
        } else {
          Serial.println("\n...Serial Number Write Completed Without Errors.");
        }
      }

      if(ReadString == "SN Read") {
        int Location = EEPROM.length() - 8;
        for(int i = 0; i < 8; i++) {
          Serial.println(EEPROM.read(Location + i), HEX);
        }
      }

      if(ReadString == "ItsAUnixSystem") {
        Debug = true;
      }
    }
  }
}

void IOTest() {
  pinMode(VSwitch_Pin, OUTPUT);
  pinMode(ExtInt, OUTPUT);

  while(Serial.read() != '\r') {
    digitalWrite(VSwitch_Pin, LOW);
    digitalWrite(ExtInt, LOW);
    delay(1000);
    digitalWrite(VSwitch_Pin, HIGH);
    digitalWrite(ExtInt, HIGH);
    delay(1000);
  }
}

boolean PGTest() {
  pinMode(18, INPUT);
  if(digitalRead(18) == HIGH) return false;
  else return true;
}

void PowerTest() {
  pinMode(Ext3v3Ctrl, OUTPUT);

  while(Serial.read() != '\r') {
    digitalWrite(Ext3v3Ctrl, LOW);
    delay(1000);
    digitalWrite(Ext3v3Ctrl, HIGH);
    delay(1000);
  }

  pinMode(Ext3v3Ctrl, INPUT);
}

void I2CTest() {
  byte error, address;
  int nDevices;

  Serial.println("Scanning...");

  nDevices = 0;
  for(address = 1; address < 127; address++) {
    Wire.beginTransmission(address);
    error = Wire.endTransmission();

    if(error == 0) {
      Serial.print("I2C device found at address 0x");
      if(address < 16) Serial.print("0");
      Serial.print(address, HEX);
      Serial.println("  !");
      nDevices++;
    } else if(error == 4) {
      Serial.print("Unknown error at address 0x");
      if(address < 16) Serial.print("0");
      Serial.println(address, HEX);
    }
  }
  if(nDevices == 0)
    Serial.println("No I2C devices found\n");
  else
    Serial.println("done\n");
}

void LEDTest() {
  pinMode(BuiltInLED, OUTPUT);
  digitalWrite(BuiltInLED, HIGH);
  for(int p = 0; p < 3; p++) {
    pinMode(RGB[p], OUTPUT);
    digitalWrite(RGB[p], HIGH);
  }

  while(Serial.read() != '\r') {
    for(int i = 0; i < 3; i++) {
      digitalWrite(RGB[i], LOW);
      delay(1000);
      digitalWrite(RGB[i], HIGH);
      delay(1000);
    }
    digitalWrite(BuiltInLED, LOW);
    delay(1000);
    digitalWrite(BuiltInLED, HIGH);
    delay(1000);
  }
}

void ADCDisp() {
  while(Serial.read() != '\r') {
    Serial.print("Ref = ");
    Serial.print(analogRead(VRef_Pin) * (3.3 / 1024.0));
    Serial.println(" V");

    Serial.print("Therm = ");
    Serial.print(analogRead(ThermSense_Pin) * (3.3 / 1024.0));
    Serial.println(" V");

    Serial.print("Bat = ");
    Serial.print(analogRead(BatSense_Pin) * (3.3 / 1024.0) / 10.0);
    Serial.println(" V");

    Serial.print("Ax = ");
    Serial.print(adc.getVoltage() * (3.3 / 1024.0));
    Serial.println(" V");

    Serial.print("\n\n");
  }
}

boolean TestSD() {
  boolean SDError = false;
  pinMode(SD_CS, OUTPUT);
  SPI.setDataMode(SPI_MODE0);
  SPI.setClockDivider(SPI_CLOCK_DIV2);

  if(!SD_Init) {
    if(!SD.begin(SD_CS)) {
      if(Debug) Serial.println("Failed Init");
      SDError = true;
      return SDError;
    }
    if(Debug) Serial.println("Initialized");
    SD_Init = true;
  }

  String FileName = "HWTest";
  (FileName + ".txt").toCharArray(FileNameC, 11);
  SD.remove(FileNameC);

  randomSeed(millis());
  int RandVal = random(30557); // number of words in Hamlet
  char RandDigits[5] = {0};
  sprintf(RandDigits, "%d", RandVal);
  int RandLength = (int)((ceil(log10(RandVal)) + 1) * sizeof(char));

  if(Debug) {
    Serial.print("Random Value = ");
    Serial.println(RandVal);
  }

  File DataWrite = SD.open(FileNameC, FILE_WRITE);
  if(DataWrite) {
    DataWrite.println(RandVal);
    DataWrite.println("\nHe was a man. Take him for all in all.");
    DataWrite.println("I shall not look upon his like again.");
    DataWrite.println("-Hamlet, Act 1, Scene 2");
  }
  DataWrite.close();

  char TestDigits[5] = {0};
  File DataRead = SD.open(FileNameC, FILE_READ);
  if(DataRead) {
    DataRead.read(TestDigits, RandLength);

    if(Debug) Serial.print("Received Value = ");
    for(int i = 0; i < RandLength - 1; i++) {
      if(Debug) Serial.print(TestDigits[i]);
      if(TestDigits[i] != RandDigits[i]) {
        SDError = true;
      }
    }
    if(Debug) Serial.println("");

    if(Debug) {
      Serial.println("SD Test Data:");
      while(DataRead.available()) {
        Serial.write(DataRead.read());
      }
    }
  }
  DataRead.close();

  if(Debug) Serial.println("");

  return SDError;
}

boolean TestClock() {
  boolean ClockError = false;
  boolean DumbFalse = false;
  Clock.setClockMode(false); // 24h
  byte DateSet[] = {63, 4, 5, 4, 20, 0, 0};
  byte DateRead[7] = {0};

  Clock.setYear(DateSet[6]);
  Clock.setMonth(DateSet[5]);
  Clock.setDate(DateSet[4]);
  Clock.setDoW(DateSet[3]);
  Clock.setHour(DateSet[2]);
  Clock.setMinute(DateSet[1]);
  Clock.setSecond(DateSet[0]);

  delay(5000);

  DateRead[6] = Clock.getYear();
  DateRead[5] = Clock.getMonth(DumbFalse);
  DateRead[4] = Clock.getDate();
  DateRead[3] = Clock.getDoW();
  DateRead[2] = Clock.getHour(DumbFalse, DumbFalse);
  DateRead[1] = Clock.getMinute();
  DateRead[0] = Clock.getSecond();

  for(int i = 6; i > 0; i--) {
    if(DateRead[i] != DateSet[i]) ClockError = true;
  }
  if(DateRead[0] != DateSet[0] + 5 && DateRead[0] != DateSet[0] + 4 && DateRead[0] != DateSet[0] + 6)
    ClockError = true;

  if(Debug) {
    Serial.println("Values Set:");
    Serial.print("Year = "); Serial.print("20"); Serial.println(DateSet[6]);
    Serial.print("Month = "); Serial.println(DateSet[5]);
    Serial.print("Day = "); Serial.println(DateSet[4]);
    Serial.print("DoW = "); Serial.println(DateSet[3]);
    Serial.print("Hour = "); Serial.println(DateSet[2]);
    Serial.print("Minute = "); Serial.println(DateSet[1]);
    Serial.print("Second = "); Serial.println(DateSet[0]);

    Serial.println("\nValues Read:");
    Serial.print("Year = "); Serial.print("20"); Serial.println(DateRead[6]);
    Serial.print("Month = "); Serial.println(DateRead[5]);
    Serial.print("Day = "); Serial.println(DateRead[4]);
    Serial.print("DoW = "); Serial.println(DateRead[3]);
    Serial.print("Hour = "); Serial.println(DateRead[2]);
    Serial.print("Minute = "); Serial.println(DateRead[1]);
    Serial.print("Second = "); Serial.println(DateRead[0]);
    Serial.println("");
  }
  return ClockError;
}

void ButtonTest() {
  pinMode(2, INPUT);
  long Timeout = 2000;
  long Time = millis();
  while(millis() - Time < Timeout) {
    if(digitalRead(2) == LOW) {
      Serial.println("Log Button Pushed");
      while(digitalRead(2) == LOW);
    }
  }
  Serial.println("Test Complete");
}

String bool2pf(boolean TestResult) {
  if(TestResult) return "FAIL";
  return "PASS";
}

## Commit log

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2018-03-01 Preliminary layout done, fixed led issue
    Finished with first round layout, changed supply voltage for LEDs to be 3v3 instead of VUSB so that alive led can work regardless of use of USB voltage
    [Blackfoot.brd, Blackfoot.sch]
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2018-04-12 Updated board, fixed software logging time
    Cleaned up traces on board, changed battery in schematic, updated logging program to have 15 minute interval by default
    [Margay.brd, Margay.sch]
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2018-05-03 Added stencil files and updated/fixed logger code
    Added solder stencil files and fixed the temp conversion issue in the logger code, and added a blink to indicate when the log button is pressed
    [Margay_v1_Stencil.SLDPRT, Margay_v1_Stencil.STL, Margay_v1_StencilPrint.dxf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]
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2018-06-06 Updated board to account for part changes
    Fixed issue where 2x1 connectors displaced, also updated passives to new sizes
    [Margay.brd, Margay.sch]
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2018-06-28 Updated test files, pick and place info, and fixed part info
    [Margay.brd, Margay.sch]
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2018-09-07 Software power fix in hardware test, added dedicated v0 and v1 test scripts
    Changed power sequencing in the hardware test script, added a dedicated v0 and v1 version for the Margay test file
2018-09-07 Fixed button layout (#14)
    Updated button layout from Cold Silicon updates, fixed resulting layout issues
    [Margay.brd, Margay.sch]
2018-09-10 Cleaned up schematic, added board and schematic images for v1.0
    Added documentation for version 1.0, added schematic PDF, board images, and updated BOM to fix ADC part number
    [Margay.brd, Margay.sch, Margay_Mrk1_BOM.csv]
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2018-09-15 Begining of v2 layout
    Power section and severl problematic signals taken care of, still need to add BME280 and fix header connections
    [Margay.brd, Margay.sch]
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2018-09-18 Cleanup and silkscreen
    Cleanup of traces, minor fix to overlap problem, relabeled silk screen to match new connections
    [Margay.brd]
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2019-01-05 Condensed headers, added bat cap, added WDT
    Condensed headers into 2 single piece headers, added capacitor on backup battery to deal with debouncing issue, also added WDT unit and replaced switched voltage output driver with unit switch instead of mosfet/comparator combo. Should double check/verify operation for WDT and integrated switch unit.
    [Margay.brd, Margay.sch]
2019-01-07 Updated to new battery
    Updated battery part to fix airwire issue
    [Margay.brd, Margay.sch]
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2019-03-21 Updated paste patterns, generated paste gerbers
    Generated solder paste gerbers and updated paste layout to be more correct (~60% on body pads)
    [Margay.brd, Margay.sch]
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2019-09-12 Updated BoM, corelated with schematic
    Fixed SD card issue, fixed 0603 vs 0402 issue
    [Margay.brd, Margay.csv, Margay.sch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]
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2021-03-01 Swap + fix SDA OB and SDA EXT jumper labels
    [Margay.brd]
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2021-04-16 No 4 screw holes: tight fit (ColdSilicon lbr)
    [Margay.brd, Margay.sch]
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2021-05-10 100K 0402 --> 0603 for easier replacement This is on the WDT-setting resistor (R10) I changed a second resistor (R19) associated with the power system to fully convert the 0402s to 0603s and keep the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
    [Margay.brd, Margay.csv, Margay.sch]
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2022-05-02 ~65:47 WDT 130K resistor 0603 1 hour logging intervals seem like a common desire. Our 100K resistor reset the logger after ~59:40, permitting a dangerous edge case (that Yuan Zeng found) by which the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
    [Margay.brd, Margay.sch]
2022-05-09 Fixes to v2.3 update
    - VUSB and VBUS connected
    - Moved vias from underneath USB connector
    - Separated Analog GND region from USB GND region to reduce noise
    - Fixed 3v3 routing (current limiting path between input and MCU)
    - Moved the "Project Margay" label on bottom to try to have it less disrupted by the solder-mask stops
    [Margay.brd, Margay.sch]
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2025-12-11 Change MAX 6071 to 6070 on v3.0 BoM by hand
    Unintentional v2.3 to 3.0 change: the 6070 is what we need. We should check if the 6071 or the 6070 is included in the PCB definition, now or once we transition to KiCAD.
    We noted this error because of faulty (doubled) battery-voltage readings in the cold.
    From Bobby Schulz, who found the source of the error:
    This is important because the MAX6071 does not have an internal filter and as a result the pinout changes - see Page 19 of datasheet. This pinout changes pin 1 from the filtered input (how we intended to use it) to 'Gound Force' - which has little documentation but looks to match the topology of the force/sense outputs but for low side swit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
    [Margay_BoM_3v0_-_2023-03-17.csv]
2026-05-13 Update README and CITATION.cff for v3.0
    - Add v3.0 photos (top and back/quarter-for-scale)
    - Document v3.0 as current iteration with changes from v2.2
    - Move v2.2 annotated diagrams to Past Iterations with cross-reference
    - Remove stale deprecated/SdFat notes; link updated tutorial URL
    - Document full hardware test sketch command reference
    - Fix MightyCore settings tables: split v2.0+ (1284p) from v0/v1 (644p)
    - Update sample code constructor to Margay Logger(MODEL_3v0)
    - Fix library reference URL (NorthernWidget-Skunkworks → NorthernWidget)
    - Update CITATION.cff to v3.0.0, date 2023-08-01
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2026-05-13 Add Hardware/Margay: intermediate KiCAD port attempt (library files only)
    Main schematic and PCB files are absent -- only autosave files existed
    locally and are excluded by .gitignore. See README and issue #41.
    Also fix .gitignore: escape leading # in \#auto_saved_files# pattern
    so it is not treated as a comment.
2026-05-13 Add Hardware/Margay_2: current KiCAD port with schematic and PCB (WIP)
    Split-sheet schematic (Margay_1/2/3.kicad_sch) and PCB layout imported
    from Eagle. Not yet verified against v3.0 production Gerbers.
    See issue #41 to track completion of the port.
    [Margay.kicad_pcb, Margay.kicad_sch, Margay_1.kicad_sch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]
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2026-05-13 README: add MargayGuide reference, field procedures, fix startup flash
    - Add link to MargayGuide PDF at top of field operator's guide
    - Correct startup flash description: long-short-short blue (was "blink blue quickly once")
    - Add Checking, SD card swap, and Downloading sections from MargayGuide
    - Fix pinout section heading and anchor (#pinout-and-board-interfaces-v22 → #pinout-and-board-interfaces)
    - Clarify v3.0 pinout is identical to v2.2 (not "annotations forthcoming")
2026-05-13 README: fix stale Skunkworks URL, USB callout, and version naming
    - Fix serial number sketch link: NorthernWidget-Skunkworks → NorthernWidget
    - Update pinout callout #2 to note USB-C on v3.0 vs micro-USB on v2.x
    - Replace "Mrk 1.0 / Mrk 2.0" with "v0.0/v1.0" and "v2.0" in Developer Notes
    - Remove stale "working tirelessly to fix" text (fixed since v2.0)
2026-05-13 Rename and clean up MargayHardwareTest sketch; rewrite README software section
    Sketch (Software/MargayHardwareTest/):
    - Rename from Margay_HardwareTest_v2 — "v2" was Bobby's internal version number,
    not a board version, and caused confusion with v2.x board designations
    - Fix reversed arguments: pinMode(INPUT, 2) → pinMode(2, INPUT) in ButtonTest()
    - Remove ~80 lines of dead commented-out code and stale //FIX /DEBUG! comments
    - Preserve all test logic, the Hamlet quote, and the ItsAUnixSystem easter egg
    README:
    - Replace stale "Using Northern Widget Software" paragraph (referenced TP-Downhole
    and MS5803 — not used since early development) with accurate hardware test and
    Margay_Li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
2026-05-13 README: fix typos, stale URLs, and dual-license attribution
    - Fix Arduino IDE URL (en/main/software → en/software) in two places
    - Fix "instillation" → "installation" in MightyCore section
    - Fix "uniuqe" → "unique" in serial number section
    - Clarify dual license: hardware/docs CC-BY-SA 4.0, Software/ GPL v3
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2026-05-14 README: expand CR1220 note with explicit coin cell warning and cold-weather guidance
    - Name the CR1220 explicitly and clarify it is the sole RTC power source,
    separate from the main battery pack
    - Add cold-weather warning: standard CR1220 rated to -20°C; field failures
    in subarctic/arctic deployments likely due to coin cell brownout
    - Recommend Panasonic BR1220 (Li-CFx, -40°C to +125°C) as drop-in replacement
    for cold deployments, with DigiKey link
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2026-05-14 Tighten and correct README: programming section rewrite + consistency pass
    - Rewrote Programming section (Issue #22): removed stale hedging, cleaner
    numbered steps, consistent menu-path formatting, fixed broken SN Set paragraph
    - Fixed intro: comma splice, missing period, "micro-scale" hyphenation
    - Fixed three typos in VSwitch note (Instantanious, corespond, disctinction)
    - Promoted # Developer Notes and # Acknowledgments to ## (H1 → H2)
    - Minor: "Board files" → "board files", em-dash consistency
2026-05-30 README: correct BR1220 rating to −30°C and add BR1225A for −40°C deployments
    Prior text incorrectly stated the BR1220 is rated to −40°C; it is −30°C.
    Added the BR1225A (−40°C to +125°C) as the arctic option, with a note that
    the on-board Linx holder officially supports its 2.5mm thickness. Clarified
    that the coin cell is the sole RTC power source during sleep.
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2026-06-01 docs: add RTC power and decoupling history page
    New RTD-ready Markdown page documenting the DS3231M VCC/VBAT handoff
    problem, root causes of RTC resets across v0.0–v3.0, and proposed v3.1
    improvements (VBAT spoof, local VCC bypass cap). Includes field
    motivation: invalid timestamps from a reset clock are scientifically
    worthless data in remote-deployment instruments.
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2026-06-01 3V3 --> Schottky diode --> VCoin+. Provide a backup option for the clock if its battery fails: the main batteries of the data logger. Ideally, this would have been connected to VBat to keep the coin 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
    [Margay.kicad_pcb, Margay_3.kicad_sch]
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2026-06-01 KiCAD: populate MPN/MF/DIGIKEY fields from v3.0 BoM CSV
    72 components updated with manufacturer, MPN, and DigiKey fields from
    Margay_BoM_3v0_-_2023-03-17.csv. Fields were absent after Eagle→KiCAD
    import. C20 (new 1µF DS3231M VCC decoupling cap) assigned same part as
    C13/C14 (TMK107B7105KA-T). R22/R23 preserved as CRT0603-BY-1002ELF
    (already correct). R7/R9 skipped — BoM MPN is a 330Ω part number, wrong
    for the 1k value; needs manual correction.
    [Margay_1.kicad_sch, Margay_2.kicad_sch, Margay_3.kicad_sch]
2026-06-01 KiCAD: fix R7/R9 MPN (330Ω part number was wrong for 1k resistors)
    The v3.0 BoM CSV had RC0603FR-07330RL (330Ω) as the MPN for R7 and R9,
    but the DigiKey number and value were correct (1k). Boards were built
    correctly. Updated MPN to RC0402FR-071KL to match the actual part.
    [Margay_1.kicad_sch]
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2026-06-02 KiCAD PCB: propagate R22/R23 BoM fields from schematic; fix R22 MPN
    MPN was incorrectly set to the DigiKey order number (CRT0603-BY-1002ELFCT-ND)
    instead of the manufacturer part number (CRT0603-BY-1002ELF). Both resistors
    now have consistent MPN/MF/DIGIKEY fields matching the schematic.
    [Margay.kicad_pcb]
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2026-06-03 Hardware: add raw KiCAD v10 Eagle import as Hardware/KiCAD-v10/
    Fresh Eagle-to-KiCAD import using KiCAD v10, parallel to the existing
    KiCAD v7 import in Hardware/KiCAD/. Committed before any edits so the
    raw import state is preserved in history.
    Known issue: the v10 PCB importer creates duplicate footprints — each
    component appears twice, once with the Margay: library prefix (at 0–50 mm,
    no routing) and once with a generic name (at Eagle coordinates 125–173 mm,
    fully routed). The generic set is correct; the Margay:-prefixed set is
    orphaned. A follow-up commit will remove the orphaned set programmatically.
    [Margay.kicad_pcb, Margay.kicad_sch, Margay_2.kicad_sch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]
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2026-11-02 KiCAD: every footprint reference points at the shared nw-cold-silicon library
    fp-lib-table names the library at ${KIPRJMOD}/../../../nw-cold-silicon in
    place of the project's Margay.pretty (left in place for now). The 84 board
    footprints and 83 placed symbols' Footprint fields go from Margay:NAME to
    nw-cold-silicon:NAME by each element's Eagle package in Margay.brd, with
    SOT23-3@1 taken as SOT23-3; the sheets' 44 embedded defaults and the
    project symbol library's 265 likewise. Bodies are not yet replaced.
    Unchanged by this: the Eagle netlist check (72 of 75 nets exact, 3 with
    differences, as before the relink), ERC 76, and every file re-saves
    identically.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
2026-11-02 KiCAD: pad-to-mask clearance 0.0635 mm, Eagle's 2.5 mil stop frame, as the board rule
    Same reason as on Okapi: Margay.brd's rules set a 2.5 mil mask frame on
    every pad, the import wrote it per pad (331 of 337 pads), and the shared
    library carries no per-pad margins. DRC 401 against 398: the three new
    items are library-mismatch notes on H1, H2 and the SD slot, whose bodies
    the next commit replaces; mask bridges 0 as before.
    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
2026-11-02 KiCAD: every footprint body replaced by its nw-cold-silicon library footprint
    The 84 embedded copies from the KiCad 7 import give way to the library's
    pads and graphics, placed as before; no pad moved or changed size. KiCad
    re-saved the result. Unchanged: 1454 segments, 119 vias, every pad's net
    and every net, 3 unconnected items. DRC 402 against 401: H1 and H2 now
    match the library's 4_40_CLOSE, whose silkscreen circle the board edge
    clips, and the logo U$2 differs from the library's NWLOGO_MED. The parity
    check, quiet before, now reports 74 footprints without the MPN field their
    symbols carry and the logo as a footprint without a symbol: fields for a
    later pass, not geometry. Every instanc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
2026-11-03 KiCAD: the last 41 symbols take their definitions from nw-cold-silicon, the page frames lose their Eagle title-block texts
    The 34 GND rail symbols (26 on the importer's GND, 8 on its
    SparkFun-PowerSymbols_GND, every one already valued GND), the 6 FRAME_A_L
    page frames and J1's SDMMCWR-CRD socket (lifted into the library as
    nw-cold-silicon 668ce0d) now name the library; every placed symbol is
    nw-cold-silicon's and no import definition is left embedded. The rails
    needed no rewire: all six embedded GND variants put the pin at (0, 2.54)
    as the library's does, and the netlist is pin for pin as before (91 nets,
    323 nodes). One difference, found by rendering Margay_1 before and after
    a trial swap: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
2026-11-03 KiCAD: all four sheets on US Letter, the size of Bobby's frames
    Bobby's FRAME_A_L is ANSI A, 8.5 x 11 in landscape, the same on all
    three Eagle sheets, and his drawings fill it (273 of 279.4 mm on
    Margay_1), which no A4 page holds (Margay_3 is 212 mm tall against A4's
    210). Each drawing moves up and left by whole grid ticks onto the page
    (Margay_1 and Margay_3 by 11 and 14 ticks, Margay_2 by 12 and 14), the
    Power/Sensor divider line on Margay_3 is 2.54 mm shorter at each end so
    it stays inside the border, and H1, H2 and U$1 on Margay_1 (no wires)
    sit two ticks higher, clear of the title block's top edge. The root
    sheet takes the same paper.
    Measured on the exported pages (ink inside 2.5..27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
2026-11-03 KiCAD: J1's keepout zones placed under the SD slot
    The same rebody.py defect as Okapi's: the nine keepouts of the
    back-side SD_WURTH_WR-CRD were copied in library coordinates instead
    of being mirrored, rotated and translated to the part. Re-bodied with
    the corrected script and normalized through kicad-cli pcb upgrade;
    KiCad's own comparison now reports J1 as matching the library, the
    board re-saves identically and the pad-net table is unchanged.
    DRC: lib_footprint_mismatch 2 to 1 (the logo LOGO1 remains, as on
    Okapi); 399 to 398; 3 unconnected and 4 parity (#62) unchanged.
    Claude-Session: https://claude.ai/code/session_017F2gr2axqf8H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
2026-11-03 KiCAD: Bobby's three dividers dashed, with Eagle's endpoints
    The Eagle sheets draw three short-dashed lines on the drawing layer
    (two on Control_Connectors, one on Power_Sensors), which the importer
    wrote as solid polylines; KiCad's nearest stroke is "dash". The
    Power_Sensors line had been shortened to stay inside the sheet border
    and is back at Bobby's endpoints, from 3.81 mm below the top of the
    page to its bottom edge, mapped from Eagle by the same offset as every
    part on the sheet (34 of 34 agree). Two more short-dashed wires in the
    Eagle file belong to symbol definitions, not to a sheet. KiCad
    re-saves all four sheets identically; Eagle nets 72 of 75; ERC 50.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
2026-11-04 KiCAD: a no-connect flag on each of the 16 pins open in Eagle as well; SBU1 and SBU2 are no-connects
    Placed from ERC's own report by erc_noconnects.py (the Okapi tool,
    now taking the project name from the .kicad_pro): fifteen on Digital
    Core (the FT231X's handshake and CBUS pins among them), one each on
    Control Connectors and Power Sensors; the USB-C's two sideband labels
    replaced by flags, the board pads A8 and B8 renamed to match. The
    three pin_not_driven items on the FT231X's DSR#, DCD# and RI# go with
    them, since those pins are among the open ones. ERC 51 to 30; Eagle
    nets 72 of 75 as before; DRC 397, unconnected 3, parity 4 (#62's
    fields) as before; four sheets and the board re-save ide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
2026-11-04 KiCAD: the ISP header's pins passive and the TPS22916's output a driver (sheet copies from nw-cold-silicon 8a54c2b)
    The header's RST no longer meets the ATmega's reset output as a
    second output (pin_to_pin 1 to 0), and U8's VOUT drives its rail
    (power_pin_not_driven 8 to 7). ERC 30 to 28; Eagle nets 72 of 75;
    four sheets and the board re-save identically.
    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
2026-11-04 KiCAD: the Eagle import's wire tails trimmed and two labels snapped to the grid (erc_stubs.py)
    From ERC's own report: six wires that ran past the label or junction
    they served to a bare end are cut back to it (RX, TX and DTR on the
    FT231X, VBAT_SW and VMAIN on the TPS22916, VBAT_SW on Power Sensors),
    two bare stubs on the USB-C's sideband pins deleted, and the VUSB and
    3V3 labels moved a fifth of a tick onto the grid with their wire ends.
    unconnected_wire_endpoint 8 to 0, endpoint_off_grid 3 to 0. identical 4/4 Eagle 72/75 ERC 4 board identical 1.
    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
2026-11-04 KiCAD: default netclass via at the board's most-used size, Eagle's 5 mil annular ring (CHECKS DRC item 1)
    Margay's clearance was already Eagle's 6 mil (oshpark-2layer); the
    netclass via becomes 0.554 mm on a 0.3 mm drill, which 81 of the
    board's 119 vias are, and the minimum annular width Eagle's 5 mil
    rule as on Okapi. DRC counts unchanged by this alone.
    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
2026-11-04 KiCAD: J4's pads against its own holes and the RST via's two gaps accepted as fabricated (DRC rules)
    Each rule names the part or net and the measured geometry: the USB-C
    package's holes 0.18 mm from its pads, the RST via 0.146 and 0.152 mm
    from C20's pad and a MOSI track. hole_clearance 4 to 0, clearance 2
    to 0; DRC 11 to 5.
    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
2026-11-04 Eagle: U13 is a MAX6070BAUT18 (DIGIKEY, MPN), not a MAX6071
    U13's part attributes in the schematic and board overrode the library's
    MAX6070 with MAX6071AAUT18 (4ed24e1, 2023-03-17). The MAX6071 has no
    filter input; its pin 1 becomes a ground force, which caused the doubled
    battery-voltage readings in the cold (#44). Edited as text, since Eagle
    no longer starts on this machine: four values, identical in .sch and
    .brd. A rebuild of Eagle's BoM export, byte-identical to the 2023 export
    from the 2023 schematic, gives the same U13 row as the hand-fixed CSV.
    Claude-Session: https://claude.ai/code/session_017F2gr2X4Cbf5cXUitE8DNF
2026-11-04 Eagle: R7, R9 MPN RC0402FR-071KL (1 kΩ, 0402), as their value and DIGIKEY
    A part-level override gave R7 and R9 (the UART series resistors between
    the ATmega1284P and FT231X) the MPN RC0603FR-07330RL: 330 Ω, 0603, on
    0402 pads, while their value and DigiKey number (311-1.00KLRCT-ND) are
    1 kΩ, 0402. The library's own R0402 1K entry is RC0402FR-071KL; the
    KiCad port made the same fix (0d89e20). Edited as text in .sch and .brd.
    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
2026-11-04 Production/tools: rebuild Eagle's BoM export and check sch/brd attributes, without Eagle
    Eagle 9.6.2 no longer starts on this machine. eagle_bom.py reproduces
    Eagle's bom.ulp CSV from the .sch (byte-identical to the 2023-03-17
    export from that day's schematic); eagle_check.py compares each part's
    attributes between .sch and .brd.
    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
2026-11-04 Production: v3.0 assembly BoM rebuilt from the corrected design
    Margay_BoM_3v0_-_2026-11-04.csv comes from Hardware/Margay.sch through
    tools/eagle_bom.py. Against the 2023-03-17 CSV it differs in R7/R9
    (RC0402FR-071KL), R19 (100 kΩ), C13/C14 (Taiyo Yuden), and H1/H2, which
    lost their DNP and N/A attributes in the schematic before the August 2023
    export. The README points fab submissions at the new file and records
    which file the Caltronics run used.
    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
2026-11-04 KiCad: R19 is the 100 kΩ RC0402FR-07100KL (311-100KLRCT-ND), not the 100 Ω part
    The symbol and footprint said 100k but carried the 100 Ω Yageo number
    and Digi-Key number, the same slip f4a868f fixed on the Eagle side; the
    numbers now match the Eagle library's 100K technology and the rebuilt
    Production/Margay_BoM_3v0_-_2026-11-04.csv.
    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
2026-11-04 KiCad: C13, C14, C20 manufacturer Taiyo Yuden (was "Yaiyo Yuden")
    The typo a068fad fixed on the Eagle side, on the three 1 µF TMK107B7105KA-T
    symbols and footprints (C20 exists only on the KiCad side).
    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
2026-11-04 Production: the 2026-11-04 BoM is the record of the fix; the next run is the KiCad rc.2
    The corrected BoM fits the 2023 copper and stays as the record of the U13,
    R7/R9, and R19 fixes. The next production run uses the KiCad design
    (v3.0.0-rc.2) and its own BoM, so the README no longer says to build from it.
    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
2026-11-04 Production/README: the next run is the KiCad design as v3.1.0-rc.2; the 2026-11-04 BoM is v3.0.0's
    Under the numbering settled on 2026-11-04, v3.0.0 is the built boards with
    their parts corrected and the KiCad board is v3.1.0.
    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
2026-11-04 Production/README: v3.0.0-rc.2 is the 2023 copper built from the corrected BoM; the KiCad board is v3.1.0
    Andy, 2026-11-04: rc.1 the boards as built, rc.2 the same copper with the
    corrected part numbers and this BoM, v3.0.0 once an rc.2 build confirms;
    the KiCad board is v3.1.0, first prerelease v3.1.0-rc.1.
    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
2026-11-05 KiCad: VSWITCH_CTRL and WD_HOLD rejoined on B.Cu past ISP1, the June reroute finished
    b82f7d8 (2026-06-01, D4 and C20 for the clock's backup power) left both
    nets open beside the RTC battery: Eagle's 7.8 mm VSWITCH_CTRL diagonal
    was gone and WD_HOLD's top-layer run from its via was displaced by 3V3.
    Both now pass between ISP1's pads 1 and 2 as parallel staircases at the
    project's 6 mil clearance, VSWITCH_CTRL outside and WD_HOLD inside,
    0.2 mm wide in the corridor; the orphan WD_HOLD via goes. Traced by a
    wire-by-wire comparison with the Eagle board: at the first import every
    one of its 1443 copper wires and 120 vias was present, and all 44 wires
    absent today left in the June rework. DRC's d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
2026-11-05 CITATION.cff: 3.0.0-rc.2, 2026-11-05
    The second release candidate of v3.0: the 2023 copper with its parts
    corrected (U13, R7/R9, R19) and the BoM that builds it. 3.0.0 follows
    once a reworked board confirms it.
    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
2026-11-05 CITATION.cff: 3.0.0, the version master now develops toward
    The release itself waits on a reworked board confirming rc.2; the
    date-released is rc.2's until then.
    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

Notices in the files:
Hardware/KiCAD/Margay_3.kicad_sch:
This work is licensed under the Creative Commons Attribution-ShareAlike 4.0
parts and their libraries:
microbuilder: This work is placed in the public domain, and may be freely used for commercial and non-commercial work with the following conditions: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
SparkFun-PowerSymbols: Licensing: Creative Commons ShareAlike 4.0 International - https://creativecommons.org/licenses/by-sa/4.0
